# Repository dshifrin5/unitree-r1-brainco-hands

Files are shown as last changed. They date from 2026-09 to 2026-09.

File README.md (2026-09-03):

# Hacking BrainCo Revo2 Dexterous Hands onto a Unitree R1 from PC2

> A complete hardware-and-software retrofit/build log for installing
> BrainCo Revo2 dexterous hands on a Unitree R1 and bringing them to
> life through the robot's PC2 computer.

## The Retrofit

This build log documents the complete retrofit: removing the original
Unitree R1 hands, installing and wiring the BrainCo Revo2 hands, fitting
custom 3D-printed wrist and PCB mounts, routing the wiring, connecting
24 V power and USB, and then configuring the existing BrainCo/Unitree
software on PC2.

> **Important:** This documents one specific Unitree R1 + BrainCo Revo2
> retrofit. Verify wiring, voltage, polarity, connectors, serial
> devices, network interfaces, and mechanical clearances on your own
> hardware before applying power or commanding motion.

------------------------------------------------------------------------

# Table of Contents

## Part I — Hardware Installation

- [1. Remove the Original Unitree R1 Hands](#1-remove-the-original-unitree-r1-hands)
- [2. Attach the BrainCo Revo2 Wiring](#2-attach-the-brainco-revo2-wiring)
- [3. Install the 3D-Printed Wrist Mount](#3-install-the-3d-printed-wrist-mount)
- [4. Route the Revo2 Wiring to the Top of the Robot](#4-route-the-revo2-wiring-to-the-top-of-the-robot)
- [5. Attach the PCB to the 3D-Printed PCB Mount](#5-attach-the-pcb-to-the-3d-printed-pcb-mount)
- [6. Connect 24 V Power and USB](#6-connect-24-v-power-and-usb)
- [7. Completed Hardware Retrofit](#7-completed-hardware-retrofit)

## Part II — Software Setup and Control

- [8. Get Inside the R1: SSH into PC2](#8-get-inside-the-r1-ssh-into-pc2)
- [9. First Check: Can PC2 See the Hands?](#9-first-check-can-pc2-see-the-hands)
- [10. Trace the Hardware at the USB Level](#10-trace-the-hardware-at-the-usb-level)
- [11. Unlock Serial-Port Access for the unitree User](#11-unlock-serial-port-access-for-the-unitree-user)
- [12. Dig Through PC2 for Existing BrainCo Code](#12-dig-through-pc2-for-existing-brainco-code)
- [13. Find Unitree's BrainCo Hand Bridge](#13-find-unitrees-brainco-hand-bridge)
- [14. Decode the Hand IDs and Serial Settings](#14-decode-the-hand-ids-and-serial-settings)
- [15. The Key Hack: Fix the Serial-Port Mismatch](#15-the-key-hack-fix-the-serial-port-mismatch)
- [16. Patch the Source Directly on PC2](#16-patch-the-source-directly-on-pc2)
- [17. Rebuild the Modified BrainCo Service](#17-rebuild-the-modified-brainco-service)
- [18. Find the R1's Actual DDS Network Interface](#18-find-the-r1s-actual-dds-network-interface)
- [19. Bring the Serial-to-DDS Bridge Online](#19-bring-the-serial-to-dds-bridge-online)
- [20. Make the Hands Move with Unitree's Built-In Test](#20-make-the-hands-move-with-unitrees-built-in-test)
- [21. Why the First Two-Hand Command Doesn't Work](#21-why-the-first-two-hand-command-doesnt-work)
- [22. Get Both BrainCo Hands Moving at the Same Time](#22-get-both-brainco-hands-moving-at-the-same-time)
- [23. Hack the Test Client for Individual Finger Control](#23-hack-the-test-client-for-individual-finger-control)
- [24. Build a Safer Single-Finger Test](#24-build-a-safer-single-finger-test)
- [25. Rebuild and Run the Modified Test](#25-rebuild-and-run-the-modified-test)

## Reference

- [File and Directory Reference](#file-and-directory-reference)
- [Quick Command Reference](#quick-command-reference)
- [What We Learned](#what-we-learned)
- [Safety and Modification Note](#safety-and-modification-note)
- [Project Summary](#project-summary)

# Part I --- Hardware Installation

## Hardware Overview

The physical retrofit was completed in six main steps:

1.  Remove the original Unitree R1 hands.
2.  Attach the BrainCo Revo2 wiring.
3.  Install the custom 3D-printed wrist mounts.
4.  Route the Revo2 wiring and connectors to the top of the robot.
5.  Attach the interface PCB to the custom 3D-printed PCB mount.
6.  Connect the hands to 24 V through the splitter and connect the PCB
    to PC2 over USB.

### Files and Images

This README assumes a repository layout similar to:

``` text
.
├── README.md
├── hardware/
│   ├── wrist-mount.stl
│   └── pcb-mount.stl
└── images/
    ├── 01-remove-original-hands.jpg
    ├── 02-revo2-wiring.jpg
    ├── 03-wrist-mount.jpg
    ├── 04-wire-routing.jpg
    ├── 05-pcb-mount.jpg
    ├── 06-power-usb.jpg
    └── 07-completed-retrofit.jpg
```

Change the filenames and image paths to match your actual repository.

------------------------------------------------------------------------

## 1. Remove the Original Unitree R1 Hands

Start by removing the original hands from the Unitree R1.

This exposes the wrist area and gives access to the mounting location
needed for the BrainCo Revo2 retrofit.

Before continuing, make sure the robot is powered down and that the
wrist area is accessible.

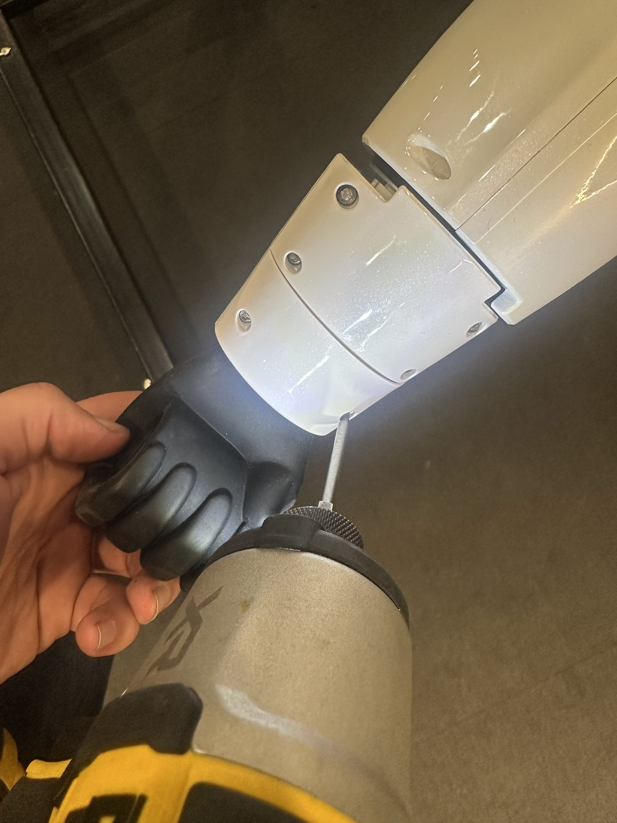
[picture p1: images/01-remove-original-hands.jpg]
Remove the original Unitree R1 hands - Step 1


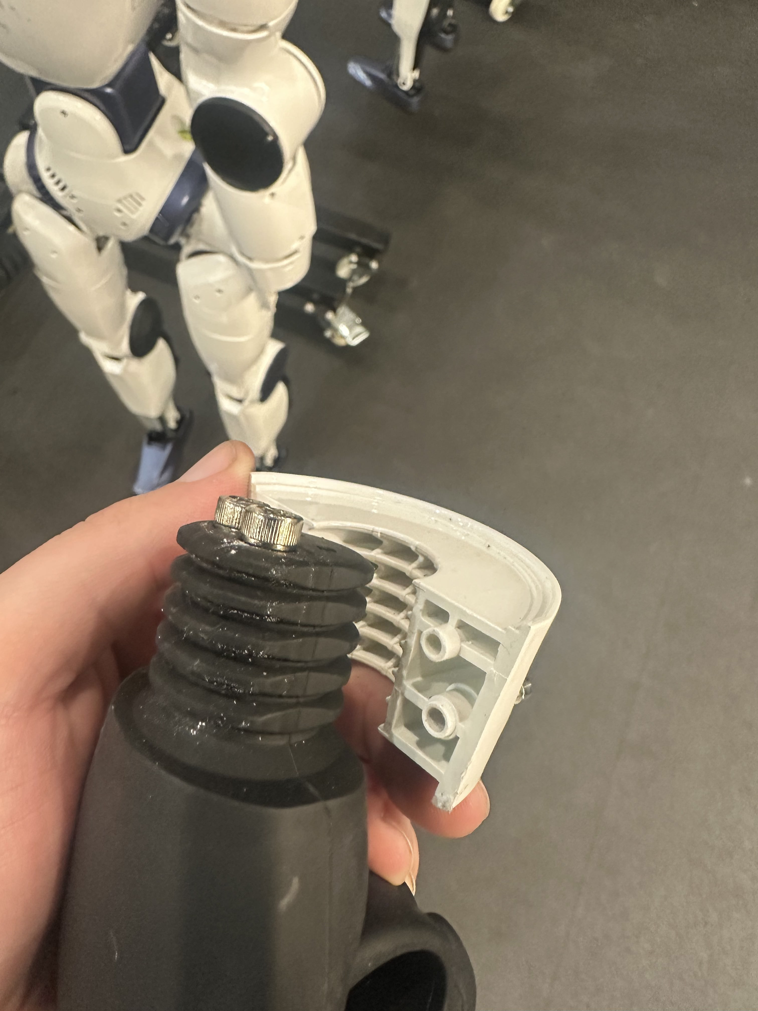
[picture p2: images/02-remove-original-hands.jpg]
Remove the original Unitree R1 hands - Step 2


------------------------------------------------------------------------

## 2. Attach the BrainCo Revo2 Wiring

With the original hands removed, attach the BrainCo Revo2 wiring.

Doing the wiring at this stage keeps the connectors accessible before
the custom wrist mount and Revo2 hand assembly are fully installed.

Make sure the wiring is seated correctly and positioned so it will not
be pinched when the wrist mount is attached.

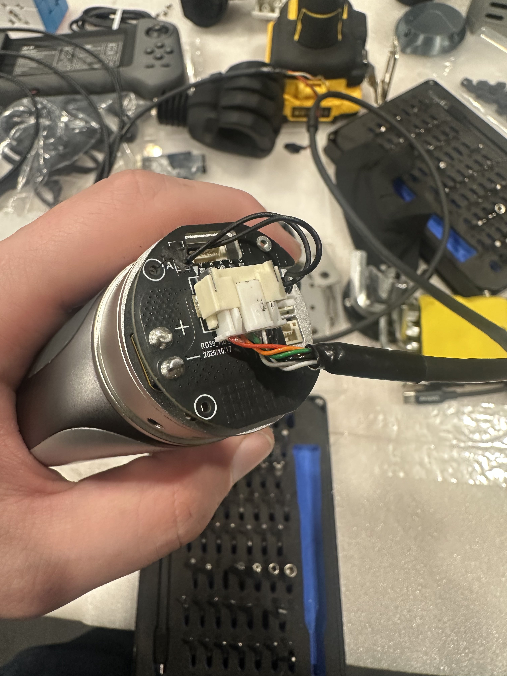
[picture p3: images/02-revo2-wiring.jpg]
Attach the BrainCo Revo2 wiring


------------------------------------------------------------------------

## 3. Install the 3D-Printed Wrist Mount

Next, install the custom 3D-printed wrist mount.

The wrist mount acts as the mechanical interface between the Unitree R1
wrist and the BrainCo Revo2 hand assembly.

The STEP used for this retrofit is stored in the repository:

``` text
hardware/wrist-mount.step
```

Position the mount correctly, make sure the Revo2 wiring remains
accessible, and secure the mount to the wrist.

Before moving on, check that:

-   The mount is seated correctly.
-   The wiring is not trapped between printed and robot parts.
-   The hand has sufficient clearance.
-   Nothing interferes with wrist motion.

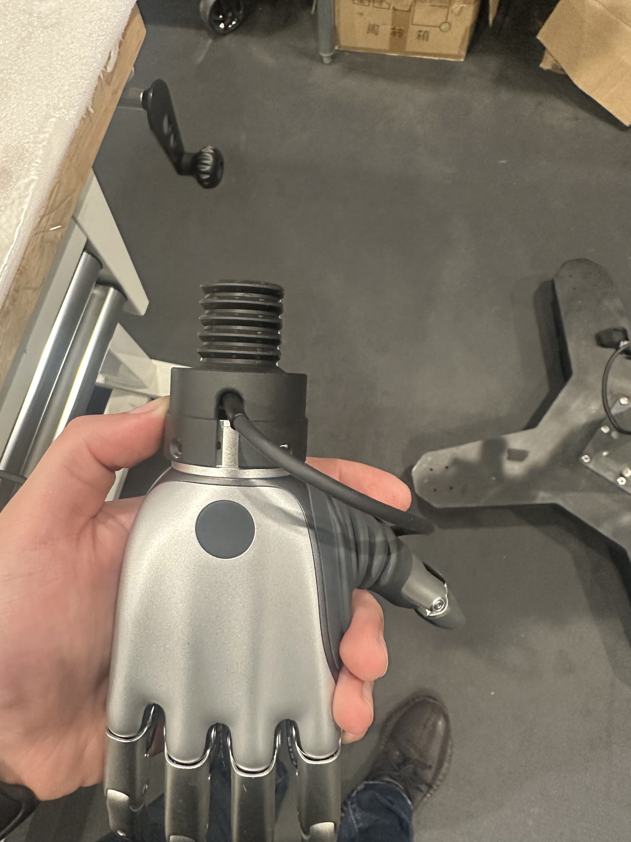
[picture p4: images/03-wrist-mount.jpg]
Install the 3D-printed wrist mount


------------------------------------------------------------------------

## 4. Route the Revo2 Wiring to the Top of the Robot

After the wrist hardware is installed, route the Revo2 wiring and
connector upward toward the top of the robot.

The goal is to bring the hand connections to the location where the
interface PCB will be mounted.

Keep the wiring:

-   Clear of moving joints.
-   Away from sharp edges.
-   Out of obvious pinch points.
-   Loose enough to allow normal joint movement.
-   Secure enough that it cannot fall into the mechanism.

Do not pull the wiring tight across an articulated joint. Leave enough
service loop for the robot's intended range of motion.

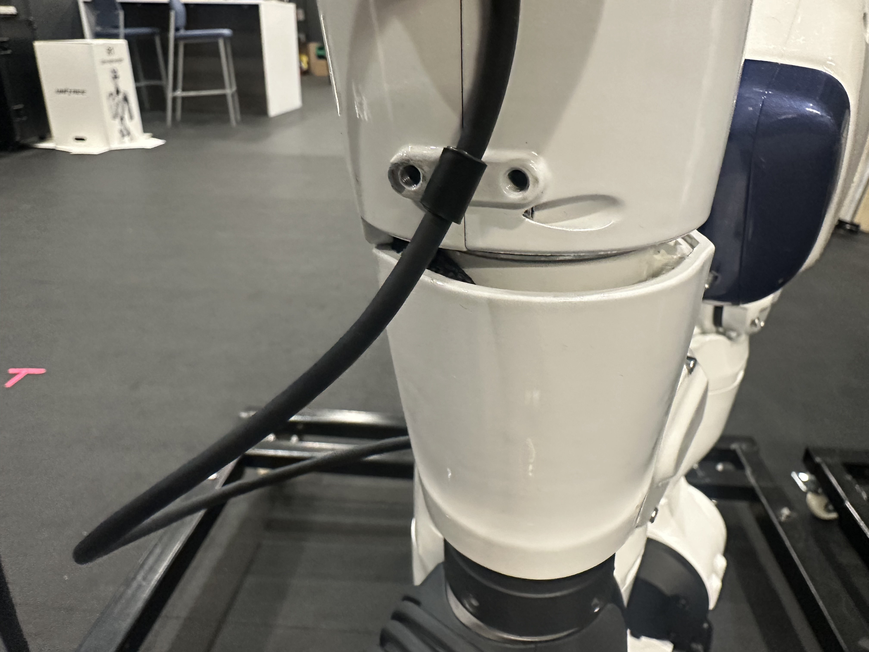
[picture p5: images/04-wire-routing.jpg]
Route the Revo2 wiring to the top


------------------------------------------------------------------------

## 5. Attach the PCB to the 3D-Printed PCB Mount

The interface PCB is mounted using a second custom 3D-printed part.

The STL for this mount is stored in the repository:

``` text
hardware/pcb-mount.stl
```

Attach the PCB to the printed mount, then secure the mount to the rail system on PC2.

Make sure the board is mechanically secure and that its connectors
remain accessible for the hand wiring, power, and USB connection.

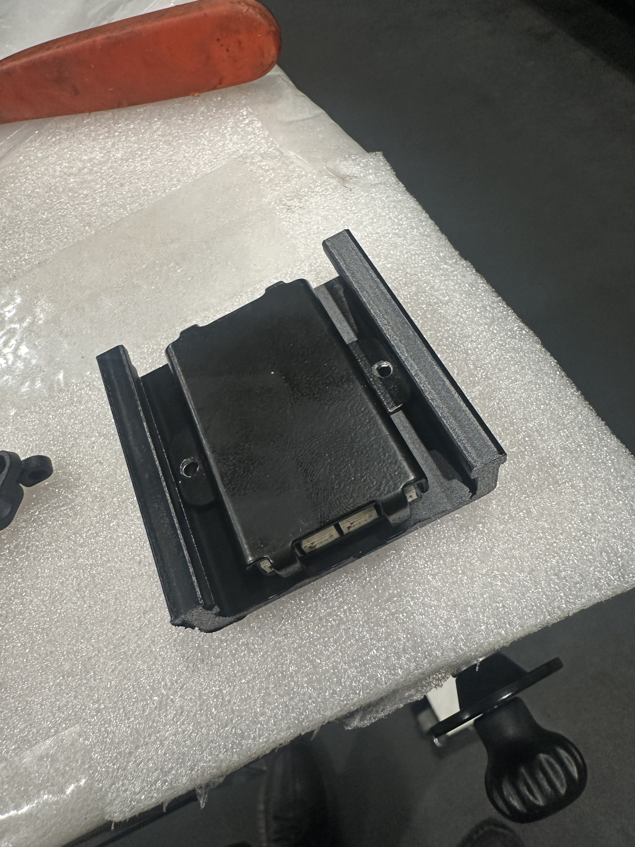
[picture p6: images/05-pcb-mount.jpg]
Attach the PCB to the 3D-printed mount

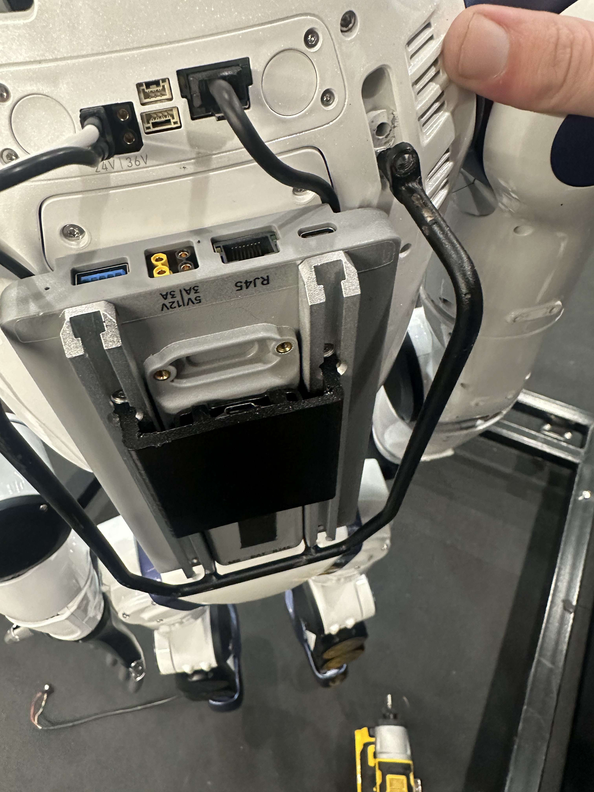
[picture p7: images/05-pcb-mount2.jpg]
Attach the PCB to the 3D-printed mount


------------------------------------------------------------------------

## 6. Connect 24 V Power and USB

With the hands, wiring, and PCB installed, make the final electrical
connections.

### Hand Power

Connect the BrainCo hand power to **24 V through the splitter**.

``` text
24 V Supply
     │
     ▼
  Splitter
   /    \
  ▼      ▼
Left    Right
Hand    Hand
```

Before applying power, verify the connector orientation, voltage, and
polarity for the hardware being used.

### PCB USB Connection

Connect the USB cable from the interface PCB to the Unitree R1 PC2.

The complete hardware communication path is now:

``` text
BrainCo Revo2 Hands
        │
        ▼
Revo2 Wiring
        │
        ▼
Interface PCB
        │
       USB
        │
        ▼
Unitree R1 PC2
```

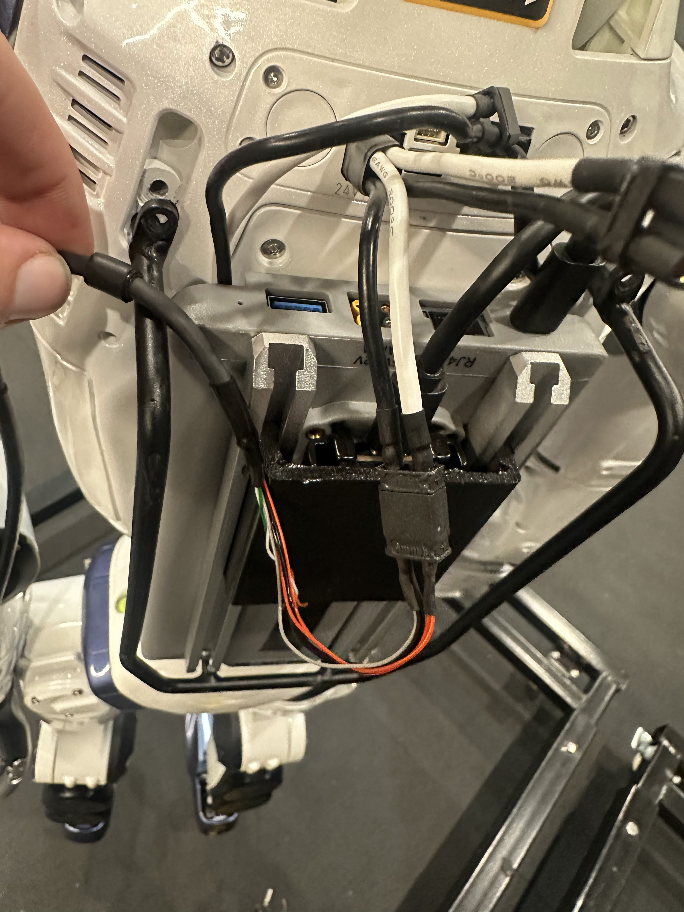
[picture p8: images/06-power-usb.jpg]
Connect 24 V power and PCB USB


------------------------------------------------------------------------

## 7. Completed Hardware Retrofit

At this point:

-   The original R1 hands have been removed.
-   BrainCo Revo2 wiring has been installed.
-   The custom wrist mounts are installed.
-   The wiring has been routed to the top.
-   The PCB is secured to its custom printed mount.
-   Hand power is connected to 24 V through the splitter.
-   The PCB is connected to PC2 over USB.

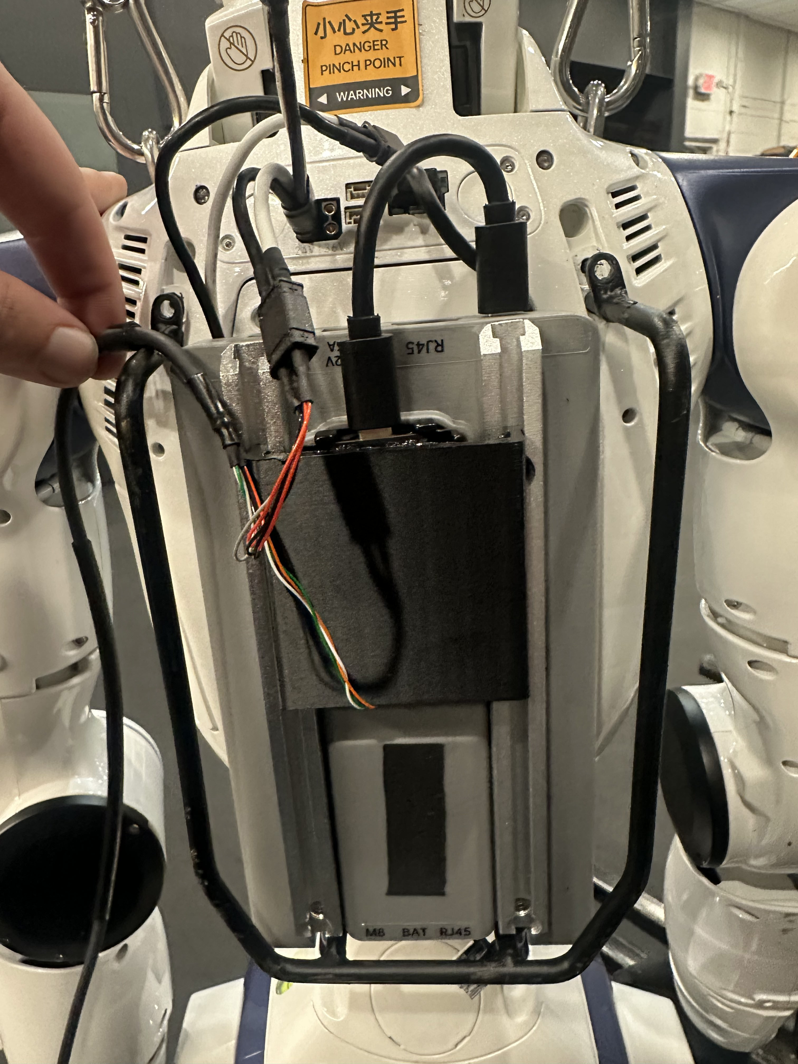
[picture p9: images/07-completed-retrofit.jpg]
Completed BrainCo Revo2 retrofit on Unitree R1


The next step is to move to PC2 and verify that Linux can actually see
the newly connected hand interface.

------------------------------------------------------------------------

# Part II --- Software Setup and Control

## DDS Topics

The BrainCo service creates separate DDS command and state topics for
the left and right hands:

``` text
rt/brainco/left/cmd
rt/brainco/left/state
rt/brainco/right/cmd
rt/brainco/right/state
```

Each hand exposes six normalized controls:

    Index Control
  ------- -----------------
        0 Thumb
        1 Thumb auxiliary
        2 Index
        3 Middle
        4 Ring
        5 Pinky

Finger position and speed are represented on a normalized `0.0–1.0`
scale.

------------------------------------------------------------------------

## 8. Get Inside the R1: SSH into PC2

The software work was performed directly on the R1's PC2 computer over
SSH.

Once connected, the shell looked like:

``` bash
unitree@ubuntu:~$
```

Before hacking on the hand-control software, first make sure Linux can
actually see the hand interface.

------------------------------------------------------------------------

## 9. First Check: Can PC2 See the Hands?

``` bash
ls -l /dev/ttyUSB*
```

Initially this returned:

``` text
ls: cannot access '/dev/ttyUSB*': No such file or directory
```

Also check both common Linux USB serial device types:

``` bash
ls -l /dev/ttyACM* /dev/ttyUSB* 2>/dev/null
```

Nothing appeared.

At that point, the problem was clearly below the SDK/application layer.
There was no point modifying BrainCo software until Linux could actually
detect the hardware.

------------------------------------------------------------------------

## 10. Trace the Hardware at the USB Level

Run:

``` bash
lsusb
```

Initially PC2 only reported its root hubs:

``` text
Bus 002 Device 001: ID 1d6b:0003 Linux Foundation 3.0 root hub
Bus 001 Device 001: ID 1d6b:0002 Linux Foundation 2.0 root hub
```

After reconnecting the hand interface, `lsusb` showed:

``` text
Bus 001 Device 004: ID 0403:6011 Future Technology Devices International, Ltd FT4232H Quad HS USB-UART/FIFO IC
```

This was the first real breakthrough on the software side of the
retrofit.

PC2 was seeing an **FTDI FT4232H Quad HS USB-UART/FIFO**.

The kernel recognized it and created four serial interfaces:

``` text
/dev/ttyUSB0
/dev/ttyUSB1
/dev/ttyUSB2
/dev/ttyUSB3
```

The FT4232H is a four-channel device, which explains why one physical
USB device produced four `/dev/ttyUSB` entries.

Confirm:

``` bash
ls -l /dev/ttyUSB*
```

Output:

``` text
crw-rw---- 1 root dialout 188, 0 /dev/ttyUSB0
crw-rw---- 1 root dialout 188, 1 /dev/ttyUSB1
crw-rw---- 1 root dialout 188, 2 /dev/ttyUSB2
crw-rw---- 1 root dialout 188, 3 /dev/ttyUSB3
```

Another useful command is:

``` bash
sudo dmesg -w
```

Leave it running while unplugging and reconnecting the USB interface.
Linux should enumerate the FTDI device and attach the individual serial
interfaces.

------------------------------------------------------------------------

## 11. Unlock Serial-Port Access for the `unitree` User

The serial interfaces showed:

``` text
root dialout
```

Members of the Linux `dialout` group can access these serial interfaces.

Check:

``` bash
groups
```

Originally, the `unitree` account was not a member of `dialout`.

Add it:

``` bash
sudo usermod -aG dialout unitree
```

Disconnect the SSH session and reconnect, then check again:

``` bash
groups
```

The account then included:

``` text
unitree adm dialout cdrom sudo audio dip video plugdev render i2c lpadmin gdm sambashare weston-launch gpio
```

At this point the `unitree` account could access `/dev/ttyUSB0` through
`/dev/ttyUSB3` without manually changing serial-device permissions.

------------------------------------------------------------------------

## 12. Dig Through PC2 for Existing BrainCo Code

Before installing anything new, search the existing PC2 filesystem:

``` bash
find ~ -maxdepth 4 -type d \( -iname "*brainco*" -o -iname "*revo*" -o -iname "*stark*" \) 2>/dev/null
```

This R1 already had BrainCo software on PC2.

Important directories:

``` text
/home/unitree/stark-serialport-example
/home/unitree/brainco_hand_service
```

The Stark examples included:

``` text
~/stark-serialport-example/python/revo2
~/stark-serialport-example/python/revo2_tactile_grasp
~/stark-serialport-example/python/revo2_can
~/stark-serialport-example/python/revo2_canfd
~/stark-serialport-example/linux/revo2
```

There were also Revo1 and EtherCAT examples.

Before cloning another SDK or building a new stack, check what is
already installed on the robot.

------------------------------------------------------------------------

## 13. Find Unitree's BrainCo Hand Bridge

``` bash
cd ~/brainco_hand_service
```

This directory contained the source code for the Unitree/BrainCo DDS
bridge.

Prebuilt executables:

``` text
~/brainco_hand_service/bin/
```

Check:

``` bash
ls -l ~/brainco_hand_service/bin
```

Our installation contained:

``` text
brainco_hand_server
test_brainco_hand_server
```

The first executable is the serial-to-DDS hand service. The second is a
prebuilt example client that publishes commands to the service.

  ------------------------------------------------------------------------------------------------
  Purpose                             Path
  ----------------------------------- ------------------------------------------------------------
  Main service source                 `~/brainco_hand_service/main.cpp`

  Test client source                  `~/brainco_hand_service/test/test_brainco_hand_server.cpp`

  Build directory                     `~/brainco_hand_service/build/`

  Service executable                  `~/brainco_hand_service/bin/brainco_hand_server`

  Test executable                     `~/brainco_hand_service/bin/test_brainco_hand_server`
  ------------------------------------------------------------------------------------------------

------------------------------------------------------------------------

## 14. Decode the Hand IDs and Serial Settings

Looking at `main.cpp` showed:

``` cpp
constexpr uint8_t L_id = 0x7e;
constexpr uint8_t R_id = 0x7f;
constexpr uint32_t baudrate = 460800;
```

  Setting      Value
  ------------ ----------------
  Left hand    `0x7E` / `126`
  Right hand   `0x7F` / `127`
  Baud rate    `460800`

The service initializes the BrainCo Revo2 hardware using Modbus:

``` cpp
init_cfg(
    StarkHardwareType::STARK_HARDWARE_TYPE_REVO2_BASIC,
    StarkProtocolType::STARK_PROTOCOL_TYPE_MODBUS,
    LogLevel::LOG_LEVEL_ERROR,
    1024
);
```

It then opens a serial connection and requests device information:

``` cpp
DeviceHandler* handle = modbus_open(port.c_str(), baudrate);
DeviceInfo* info = modbus_get_device_info(handle, slave_id);
```

The service can therefore query the connected device instead of simply
assuming that a serial port corresponds to a particular hand.

------------------------------------------------------------------------

## 15. The Key Hack: Fix the Serial-Port Mismatch

The supplied `main.cpp` was looking for:

``` text
/dev/ttyCH343USB0
/dev/ttyCH343USB1
```

But the FTDI interface on this R1 created:

``` text
/dev/ttyUSB0
/dev/ttyUSB1
/dev/ttyUSB2
/dev/ttyUSB3
```

The original section was:

``` cpp
if (path.rfind("/dev/ttyCH343USB0", 0) == 0)
    ports.push_back(path);

if (path.rfind("/dev/ttyCH343USB1", 0) == 0)
    ports.push_back(path);
```

For this R1, change it to:

``` cpp
if (path.rfind("/dev/ttyUSB", 0) == 0)
    ports.push_back(path);
```

That lets the service discover and probe the FT4232H serial interfaces.

> This is hardware/configuration-specific. Do not automatically make the
> same change on every R1.

First check:

``` bash
ls -l /dev/ttyUSB*
ls -l /dev/ttyCH343USB*
```

------------------------------------------------------------------------

## 16. Patch the Source Directly on PC2

This PC2 image did not have `nano`:

``` text
-bash: nano: command not found
```

`vi` was available:

``` bash
cd ~/brainco_hand_service
vi main.cpp
```

Make the serial-port change and save the file.

------------------------------------------------------------------------

## 17. Rebuild the Modified BrainCo Service

``` bash
cd ~/brainco_hand_service/build
make -j6
```

A successful build looked like:

``` text
Scanning dependencies of target brainco_hand_server
[ 25%] Building CXX object CMakeFiles/brainco_hand_server.dir/main.cpp.o
[ 75%] Built target test_brainco_hand_server
[100%] Linking CXX executable ../bin/brainco_hand_server
[100%] Built target brainco_hand_server
```

The executable is generated at:

``` text
~/brainco_hand_service/bin/brainco_hand_server
```

------------------------------------------------------------------------

## 18. Find the R1's Actual DDS Network Interface

Run:

``` bash
ip -br link
```

Our R1 PC2 showed:

``` text
lo       UNKNOWN
dummy0   DOWN
eth10    UP
docker0  DOWN
```

The relevant interface was:

``` text
eth10 UP
```

The repository README uses `eth0` as an example, but this R1 used
`eth10`.

Check the actual robot instead of assuming the interface name.

------------------------------------------------------------------------

## 19. Bring the Serial-to-DDS Bridge Online

The executable is not in the repository root, so this will fail:

``` bash
cd ~/brainco_hand_service
sudo ./brainco_hand_server
```

Instead:

``` bash
cd ~/brainco_hand_service/bin
sudo ./brainco_hand_server --network eth10
```

The modified service now acts as the bridge:

``` text
BrainCo Revo2 Hands
        ↓
Serial / Interface PCB
        ↓
brainco_hand_server
        ↓
Unitree DDS
        ↓
rt/brainco/left/...
rt/brainco/right/...
```

Keep this process running and use a separate terminal for control
commands.

------------------------------------------------------------------------

## 20. Make the Hands Move with Unitree's Built-In Test

The built-in test executable is:

``` text
~/brainco_hand_service/bin/test_brainco_hand_server
```

Its source is:

``` text
~/brainco_hand_service/test/test_brainco_hand_server.cpp
```

It publishes to:

``` text
rt/brainco/left/cmd
```

or:

``` text
rt/brainco/right/cmd
```

Test the left hand:

``` bash
cd ~/brainco_hand_service/bin
sudo ./test_brainco_hand_server left
```

Test the right:

``` bash
sudo ./test_brainco_hand_server right
```

The stock test cycles through:

``` cpp
positions = {0, 0, 0, 0, 0, 0};
```

then:

``` cpp
positions = {0, 1, 1, 1, 1, 1};
```

then:

``` cpp
positions = {1, 1, 1, 1, 1, 1};
```

with delays between commands.

This confirmed that all six hand DOFs could be commanded through DDS.

------------------------------------------------------------------------

## 21. Why the First Two-Hand Command Doesn't Work

This does **not** run both hands:

``` bash
sudo ./test_brainco_hand_server left && right
```

In Bash, `&&` runs the next shell command only after the previous
command exits successfully. Bash therefore interprets `right` as another
executable.

Likewise:

``` bash
sudo ./test_brainco_hand_server left &&
sudo ./test_brainco_hand_server right
```

runs them sequentially rather than simultaneously.

------------------------------------------------------------------------

## 22. Get Both BrainCo Hands Moving at the Same Time

Run both test programs concurrently:

``` bash
cd ~/brainco_hand_service/bin

sudo ./test_brainco_hand_server left &
sudo ./test_brainco_hand_server right &
wait
```

The `&` backgrounds each process.

``` text
                    brainco_hand_server
                            │
              ┌─────────────┴─────────────┐
              │                           │
   rt/brainco/left/cmd          rt/brainco/right/cmd
              ↑                           ↑
      left test process             right test process
```

Stop the test processes with:

``` bash
sudo pkill -f test_brainco_hand_server
```

------------------------------------------------------------------------

## 23. Hack the Test Client for Individual Finger Control

The six-element array corresponds to:

``` text
[Thumb, Thumb_aux, Index, Middle, Ring, Pinky]
```

  Finger              Array Element
  ----------------- ---------------
  Thumb                           0
  Thumb auxiliary                 1
  Index                           2
  Middle                          3
  Ring                            4
  Pinky                           5

For example:

``` cpp
positions[2] = 1.0f;
```

changes the requested index-finger position.

This:

``` cpp
cmds()[2].q() = 1.0;
```

cannot be entered directly into Bash because it is C++ source code.

Modify:

``` text
~/brainco_hand_service/test/test_brainco_hand_server.cpp
```

and rebuild it.

------------------------------------------------------------------------

## 24. Build a Safer Single-Finger Test

For individual-finger testing, read the current hand state first and
preserve the other five positions.

State topics:

``` text
rt/brainco/left/state
rt/brainco/right/state
```

Read the current positions:

``` cpp
std::array<float, 6> positions;

for (int i = 0; i < 6; ++i)
{
    positions[i] = lowstate->msg_.states()[i].q();
}
```

Change only the index:

``` cpp
positions[2] = 1.0f;
```

Publish:

``` cpp
for (int i = 0; i < 6; ++i)
{
    lowcmd->msg_.cmds()[i].q() = positions[i];
}

lowcmd->unlockAndPublish();
```

Then send the opposite endpoint:

``` cpp
positions[2] = 0.0f;
```

For initial testing, finger speed was reduced from:

``` cpp
finger.dq() = 1.0f;
```

to:

``` cpp
finger.dq() = 0.3f;
```

so the first experimental movement could be slower.

------------------------------------------------------------------------

## 25. Rebuild and Run the Modified Test

After modifying:

``` text
~/brainco_hand_service/test/test_brainco_hand_server.cpp
```

recompile:

``` bash
cd ~/brainco_hand_service/build
make -j6
```

Then:

``` bash
cd ~/brainco_hand_service/bin
sudo ./test_brainco_hand_server left
```

or:

``` bash
sudo ./test_brainco_hand_server right
```

------------------------------------------------------------------------

# File and Directory Reference

  ------------------------------------------------------------------------------------------------
  Item                                Location
  ----------------------------------- ------------------------------------------------------------
  BrainCo/Unitree service             `~/brainco_hand_service/`

  Main serial-to-DDS source           `~/brainco_hand_service/main.cpp`

  Service executable                  `~/brainco_hand_service/bin/brainco_hand_server`

  Control/test source                 `~/brainco_hand_service/test/test_brainco_hand_server.cpp`

  Control/test executable             `~/brainco_hand_service/bin/test_brainco_hand_server`

  Build directory                     `~/brainco_hand_service/build/`

  Additional BrainCo/Stark examples   `~/stark-serialport-example/`

  Python Revo2 examples               `~/stark-serialport-example/python/revo2/`

  Linux Revo2 examples                `~/stark-serialport-example/linux/revo2/`

  Custom wrist mount                  `hardware/wrist-mount.stl`

  Custom PCB mount                    `hardware/pcb-mount.stl`
  ------------------------------------------------------------------------------------------------

------------------------------------------------------------------------

# Quick Command Reference

### Check USB hardware

``` bash
lsusb
```

### Check serial interfaces

``` bash
ls -l /dev/ttyUSB*
```

### Watch USB connections

``` bash
sudo dmesg -w
```

### Check serial permissions

``` bash
groups
```

### Add `unitree` to `dialout`

``` bash
sudo usermod -aG dialout unitree
```

Reconnect SSH afterward.

### Find existing BrainCo software

``` bash
find ~ -maxdepth 4 -type d \( -iname "*brainco*" -o -iname "*revo*" -o -iname "*stark*" \) 2>/dev/null
```

### Check network interfaces

``` bash
ip -br link
```

### Build

``` bash
cd ~/brainco_hand_service/build
make -j6
```

### Start the server on this R1

``` bash
cd ~/brainco_hand_service/bin
sudo ./brainco_hand_server --network eth10
```

### Test left

``` bash
sudo ./test_brainco_hand_server left
```

### Test right

``` bash
sudo ./test_brainco_hand_server right
```

### Test both

``` bash
sudo ./test_brainco_hand_server left &
sudo ./test_brainco_hand_server right &
wait
```

### Stop tests

``` bash
sudo pkill -f test_brainco_hand_server
```

------------------------------------------------------------------------

# What We Learned

The complete retrofit path was:

``` text
Remove original R1 hands
        ↓
Attach BrainCo Revo2 wiring
        ↓
Install 3D-printed wrist mounts
        ↓
Route wiring and connectors upward
        ↓
Mount interface PCB on 3D-printed PCB mount
        ↓
Connect hand power to 24 V through splitter
        ↓
Connect PCB USB to PC2
        ↓
No /dev/ttyUSB devices
        ↓
Check lsusb
        ↓
Reconnect USB interface
        ↓
FTDI FT4232H detected
        ↓
ttyUSB0–ttyUSB3 created
        ↓
Fix dialout permissions
        ↓
Find existing BrainCo software
        ↓
Discover serial-device naming mismatch
        ↓
Rebuild brainco_hand_server
        ↓
Use correct PC2 network interface
        ↓
Start serial-to-DDS bridge
        ↓
Use existing Unitree test client
        ↓
Control left/right BrainCo hands
        ↓
Extend example for individual fingers
```

One of the biggest lessons was that a completely new software stack was
not necessary. PC2 already contained BrainCo/Stark examples and
Unitree's `brainco_hand_service`, including prebuilt binaries.

The key was connecting the physical retrofit correctly, identifying the
actual USB hardware, fixing Linux permissions, matching the
serial-device names used by the real interface, selecting the correct
DDS network interface, and then using the software that was already
present.

------------------------------------------------------------------------

# Safety and Modification Note

This project documents one specific Unitree R1 + BrainCo Revo2
installation. Serial-device names, network interfaces, hand models,
firmware, printed mounts, wiring, connectors, and electrical
configuration may differ on another robot.

Before applying power or issuing motion commands:

-   Power down the robot while making physical or electrical changes.
-   Verify the required supply voltage, connector orientation, and
    polarity before connecting the 24 V supply.
-   Keep wiring clear of joints and pinch points.
-   Verify that 3D-printed mounts are mechanically secure.
-   Check wrist and arm clearance before enabling motion.
-   Keep hands and objects clear of the Revo2 fingers.
-   Verify which physical hand is being addressed.
-   Begin at reduced finger speed.
-   Do not assume normalized endpoints correspond to the same physical
    direction on every configuration.
-   For custom behaviors, read the current hand state and modify only
    the intended DOF rather than blindly commanding all six finger
    positions.

------------------------------------------------------------------------

# Project Summary

  Component                       Configuration
  ------------------------------- ------------------------------------
  Robot                           Unitree R1
  Hands                           BrainCo Revo2
  Computer                        Unitree R1 PC2
  Mechanical interface            Custom 3D-printed wrist mount
  PCB mounting                    Custom 3D-printed PCB mount
  Hand power                      24 V through splitter
  PC2 connection                  USB from interface PCB
  USB interface detected by PC2   FTDI FT4232H Quad HS USB-UART/FIFO
  Protocol                        Modbus
  Baud rate                       `460800`
  Left hand ID                    `0x7E` / `126`
  Right hand ID                   `0x7F` / `127`
  DDS interface on this R1        `eth10`

## DDS Topics

``` text
rt/brainco/left/cmd
rt/brainco/left/state
rt/brainco/right/cmd
rt/brainco/right/state
```

------------------------------------------------------------------------

*This README documents an experimental hardware/software retrofit and is
not an official Unitree or BrainCo integration.*

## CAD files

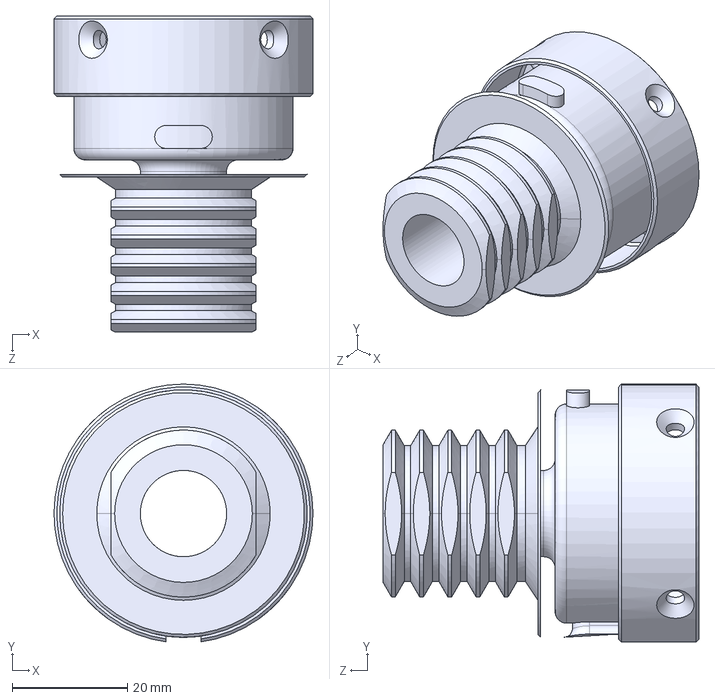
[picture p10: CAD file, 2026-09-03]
hardware/wrist-mount.step
45.0 x 44.8 x 54.9 mm

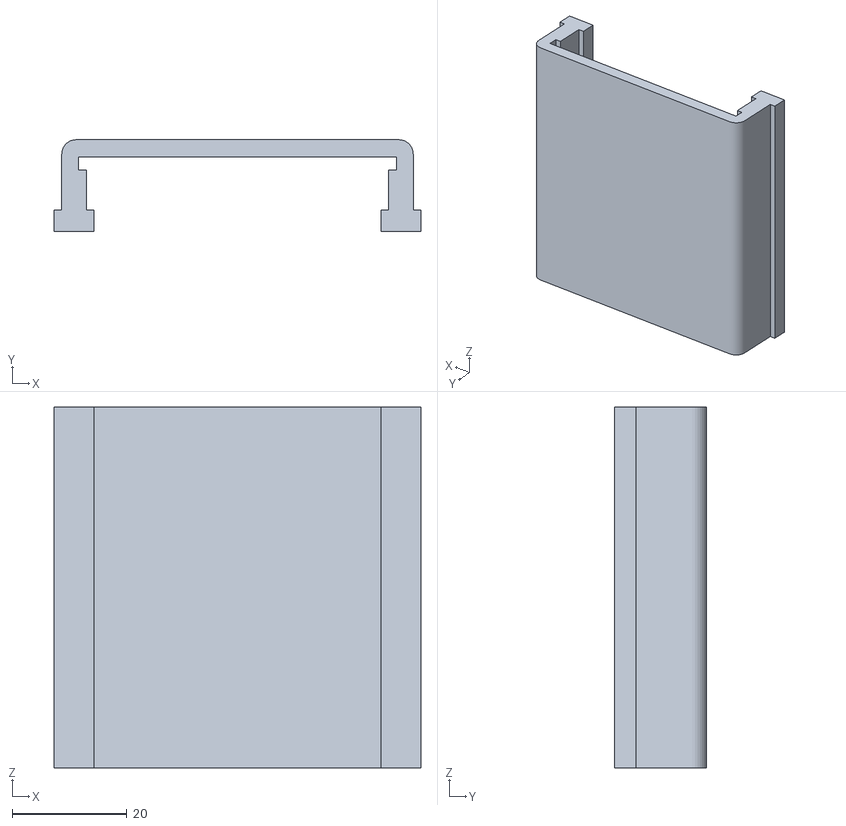
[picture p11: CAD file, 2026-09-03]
hardware/pcb-mount.stl
64.1 x 16.0 x 63.0

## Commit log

2026-09-03 Revise README by removing wiring diagram
    Removed detailed wiring diagram and updated image captions.
2026-09-03 Change STL references to STEP in README
    Updated file references from STL to STEP format for the wrist mount and PCB mount in the README.
2026-09-03 Enhance README with Table of Contents and PCB instructions
    Added a Table of Contents to improve navigation and updated instructions for securing the PCB mount.
